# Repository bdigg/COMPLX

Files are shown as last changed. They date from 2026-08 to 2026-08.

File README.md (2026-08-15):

# COMPLX Control Software

COMPLX is the control software for a robotic-microfluidic platform for
combinatorial lipid nanoparticle formulation. It coordinates a DOBOT MG400 input
robot, pressure-driven microfluidic flow control, Arduino-compatible collection
hardware, experiment scheduling, live status updates, and run logging for
plate-based formulation workflows.

This repository accompanies the manuscript *A robotic-microfluidic platform for
combinatorial access to millions of lipid nanoparticle formulations*. It
contains the Python control software, Arduino firmware, public configuration
templates, example experiment import data, and the hardware bill of materials
in `Part Files and BOM/`.

## Platform Overview

COMPLX combines three hardware subsystems:

- DOBOT MG400 robotic input handling for loading lipid stocks and carrying out
  automated line changes.
- Elveflow OB1 pressure-driven microfluidic control with inline flow sensing.
- Arduino-controlled output hardware for plate collection and valve actuation.

The software communicates with the DOBOT over TCP/IP, with the Elveflow OB1
through the manufacturer Python interface, and with the collection stage and
servo-actuated valves through serial communication. Hardware addresses, COM
ports, calibration values, and control parameters are stored in `configs/`, so
the platform can be adapted without modifying source code.

In the workflow described in the associated paper, COMPLX is used to select from
lipid stock libraries, generate or import formulation spaces, assign output
wells in 96- or 384-well plate layouts, schedule stock changes, control
microfluidic formulation, and record full run data.

## Installation And Setup

These instructions assume the hardware has been assembled as described in the
associated manuscript and supplementary methods.

### 1. Install Conda

Install a 64-bit Conda distribution for Windows.

### 2. Create A Python Environment

Create and activate a dedicated environment:

```powershell
conda create -n complx python=3.12
conda activate complx
```

Python 3.11 or newer is expected. Python 3.12.2 was used for the manuscript
experiments.

### 3. Install Python Packages

Install the Python dependencies:

```powershell
python -m pip install -r requirements.txt
```

### 4. Install Elveflow Software And Drivers

Install the Elveflow software, SDK, runtime components, and drivers for the OB1
controller and flow sensors:

https://elveflow.com/microfluidic-applications/setup-environment-elveflow-sdk/

Elveflow vendor files are not included in this repository. Users must obtain
them from Elveflow and install them locally. The COMPLX Python modules expect the
Elveflow Python wrapper (`Elveflow64.py`) and 64-bit DLL/runtime files to be
available locally before connecting to the OB1.

### 5. Set Up The DOBOT MG400

Install DOBOT Studio Pro and connect the MG400 over Ethernet:

https://www.dobot-robots.com/service/download-center

Configure the robot controller network settings, then load and run the included
`dobotserver.lua` script on the DOBOT before connecting from the COMPLX software.

Perform setup and calibration of the robotic arm as described in the manuscript
methods.

### 6. Set Up The Arduino Hardware

Install the Arduino IDE. In the Arduino IDE:

- Connect the Arduino controlling the collection stage.
- Select the correct board and COM port.
- Upload `arduino/arduino.ino`.
- If secondary valves are used, upload `arduino/arduino_secondary_valves.ino` to
  the secondary controller.

The collection-stage and valve controllers communicate with COMPLX over serial.
The manuscript workflow used serial communication at 115200 baud. If multiple
serial devices are attached, select the intended COM ports in the GUI or local
configuration before running automated collection.

### 7. Configure Local Settings

Hardware and app settings must be configured in the GUI before operation. The
GUI saves these selections and calibration values in `configs/` for reuse.

Key local settings include:

- Elveflow controller identifiers and optional extra pressure-controller
  settings.
- DOBOT IP address and port.
- Arduino COM ports for the collection stage and secondary valves.
- Sensor channel assignments and correction coefficients.
- Pressure limits, flow-control gains, timing parameters, and flush settings.
- Plate format, starting position, excluded wells, and plate calibration.

The saved config files will contain local serial numbers, COM ports, IP
addresses, calibration arrays, and run settings.

## Running COMPLX

From this folder, with the environment activated:

```powershell
python main.py
```

or, after editable installation:

```powershell
complx
```

The GUI creates runtime folders as needed and uses the configuration files in
`configs/` for hardware and run settings.

## Operating Workflow

The typical operating method follows this general sequence:

1. Start the hardware systems and launch COMPLX in the configured Conda
   environment by running main.py.
2. Connect to the pressure controller, DOBOT, collection stage, and valve
   microcontrollers through the software interface.
3. Select a user configuration defining timing, flow-control settings, sensor
   calibration, pressure limits, and active hardware.
4. Populate the digital lipid library with stock names, identifiers,
   concentrations, display colours, input-plate positions, and loading volumes.
5. Fill the corresponding input wells with the required lipid stock volume plus
   excess dead volume for robotic loading, then seal wells as required by the
   hardware workflow.
6. Record the aqueous phase or buffer and connect the buffer reservoir to the
   microfluidic manifold.
7. Create experiments in the GUI or import them from CSV. Each experiment defines
   lipid stocks, component ratios, total flow rate, flow-rate ratio, collection
   volume, repeats, and output wells.
8. Confirm output plate format, destination wells, excluded positions, and
   collection-plate placement.
9. Connect the microfluidic device to the lipid inlets, aqueous inlet, and
   particle outlet.
10. Inspect tubing, reservoirs, waste routing, robotic alignment, collection
   stage position, and plate seating.
11. Prime or flush lines, start the queue, and monitor live flow, pressure,
   robot, and collection status.
12. After completion, remove collection plates and run the final cleaning
   procedure.

## Outputs

During use the software creates local runtime and output folders:

- `logs/` - finalized JSON logs and run indexes.
- `FlowData/` - run folders, parameter records, flow traces, plots, and Excel
  logs.

For each formulation, the logging system records identifiers, lipid identities,
programmed compositions, assigned input and output wells, target and measured
flow rates, pressure set points, collection volume, equilibration and expulsion
timing, run events, status, and time-series flow data.

## Admin Tools

The GUI includes admin tools for setup, calibration, and troubleshooting. These
tools allow manual control of selected hardware functions, including DOBOT
movement, gripper and valve outputs, collection-stage movement, plate-position
calibration, sensor checks, priming, and cleaning routines.

Admin tools should be used only by trained operators during setup or fault
recovery. Confirm that pressure is safe, the collection stage is clear, and the
robot work envelope is unobstructed before using manual movement controls.

## First Run Checks

Before allowing pressure control or movement:

- Confirm tubing, reservoirs, waste routing, and chip connections are secure.
- Confirm pressure limits in `configs/app/config.json` are conservative for the
  chip and formulation.
- Confirm sensor channels and correction coefficients match the connected
  hardware.
- Confirm collection plate calibration and starting well are correct.
- Confirm the DOBOT, Arduino hardware, and Elveflow hardware can be stopped
  manually.
- Confirm destination wells are empty and the plate is correctly seated.
- Confirm the microfluidic outlet is directed to waste during priming and
  failure recovery.

## Safety Checklist

- Ensure a full local risk assessment is in place before operating the COMPLX
  platform.
- Verify tubing, reservoirs, waste routing, and chip connections before enabling
  pressure.
- Use conservative `p_range`, `p_incr`, and flow-rate values when testing new
  chips, sensors, or formulations.
- Keep hands clear of the robot and collection stage during automated motion.
- Confirm collection wells are empty before automated dispensing.
- Confirm pressure and robot emergency-stop procedures before unattended runs.
- Stop the run immediately if flow readings, pressure readings, or robot motion
  do not match the expected state.

## License

This software is released under the MIT License. See `LICENSE`.

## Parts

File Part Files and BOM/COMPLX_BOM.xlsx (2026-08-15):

Mechanical and Electronic
Item | Number | Description | Supplier | Link | Cost/Unit | Total
Robot Arm | 1 | With electromagnetic gripper | Robot Shop | https://uk.robotshop.com/products/dobot-mg400-robotic-arm | £1846.15 | £1846.15
Linear Actuator | 3 | 500mm | Ooznest | https://ooznest.co.uk/product/mini-v-linear-actuator-kit/#length | £47.54 | £142.62
Motor | 3 | 1704HS168AW-AB NEMA 17 stepper motor, 1.8°/step, 1.68 A, approximately 3.5 kg·cm. | Ooznest | With above, inc cable | £17.82 | £53.46
Motor Driver | 4 | DFRobot DRI0043 / TB6600 stepper driver, four units, configured to 0.5 A and 1/4 microstepping | Farnell | https://uk.farnell.com/dfrobot/dri0043/stepper-motor-driver-4a-9v-to/dp/3517878 | £18.18 | £72.72
Arduino | 2 | 2x Nano Every or 1x Uno | RS | https://uk.rs-online.com/web/p/arduino/1927590?gb=a | £11.18 | £22.36
12V DC Supply | 3 | 12 V DC, 1.5 A, 18 W | RS | https://uk.rs-online.com/web/p/ac-dc-adapters/1753310 | £10.42 | £31.26
Cable Mount | 5 |  | RS | https://uk.rs-online.com/web/p/dc-power-connectors/1792860 | £2.94 | £14.70
Mini Vacuum | 1 | AIRPO D2028B miniature vacuum pump, 12 V DC | Mouser | https://www.mouser.co.uk/ProductDetail/SparkFun/ROB-10398?qs=WyAARYrbSnaW%252B0ieELD1FQ%3D%3D | £20.96 | £20.96
Servo Motors | 10 | SG90 micro servo, 5 V | RS | https://uk.rs-online.com/web/p/stem-motion-components/2153180 | £4.04 | £40.40
Z-Axis Linear Actuator | 1 | Portescap two-phase stepper linear actuator, 8.9 N force, 48 mm travel, 12 V | RS | https://uk.rs-online.com/web/p/electric-linear-actuators/5101091?searchId=2ede3070-08aa-4e1e-927f-483a743afa06 | £108.77 | £108.77
Motor Cables | 4 | 4-Core Cables ( | RS | https://ooznest.co.uk/product/1000mm-nema17-hybrid-bipolar-stepper-motor-wire/ | £2.40 | £9.60
Limit Switch | 3 | With cables | Ooznest | https://ooznest.co.uk/product/micro-limit-switch/ | £2.50 | £7.50
Breadboard | 2 | Will require jumper wires (either soldered or solderless) | RS | https://uk.rs-online.com/web/p/breadboards/2153175 | £4.14 | £8.28
Micro USB Cable | 2 |  | RS | https://uk.rs-online.com/web/p/usb-cables/1828496 | £3.48 | £6.96
Microfluidic
Item | Number | Description | Supplier | Link | Cost/Unit | Total
Eleveflow OB1 | 1 | Four channels, 0-2bar | Darwin Microfluidics | https://darwin-microfluidics.com/products/ob1-mk4-flow-controller | £9909.30 | £9909.30
Bottle Reservoir Cap | 1 | For 1L Duran Bottle, PTFE | Darwin Microfluidics | https://darwin-microfluidics.com/products/microfluidic-caps-and-glass-reservoir-bottle | £129.70 | £129.70
40ml Reservoir Cap | 3 | For 40ml Falcon Tubes | Darwin Microfluidics | https://darwin-microfluidics.com/products/50-ml-falcon-tube-microfluidic-reservoir-m-2-4-port | £134.50 | £403.50
1/4-28 Flangless Fittings | 3 | (Pack of 10 inc ferrules) | Darwin Microfluidics | https://darwin-microfluidics.com/products/microfluidic-flangeless-fittings-1-4-28-to-1-16-od-tubing | £47.12 | £141.36
10-32 Flangless Fittings | 1 | For lipid library nozzle connections | Darwin Microfluidics | https://darwin-microfluidics.com/products/10-32-flat-bottom-peek-fittings-ferrules-pack-of-10 | £69.47 | £69.47
Male Luer to Barbed Adapter | 1 | For gas line connection | Darwin Microfluidics | https://darwin-microfluidics.com/products/male-luer-to-barbed-adapter-10-pack-pp/ | £8.00 | £8.00
1/4-28 to Barbed | 1 |  | Darwin Microfluidics | https://darwin-microfluidics.com/products/1-4-28-swivel-to-3-32-id-adapter-for-4-mm-tubing | £44.88 | £44.88
1/4-28 Union
Whisper Valves 3/2 | 3 | With 1/4-28 Fittings | Darwin Microfluidics | https://darwin-microfluidics.com/products/3-2-way-bistable-whisper-valve-type-6724/ | £141.90 | £425.70
Flow Sensor (1000ul/min) | 1 |  | Mouser | https://www.mouser.co.uk/ProductDetail/Sensirion/LG16-1000D-1000-ul-min?qs=xZ%2FP%252Ba9zWqakiDmqzvSsnA%3D%3D | £499.89 | £499.89
Flow Sensor (7ul/min) | 3 |  | Mouser | https://www.mouser.co.uk/ProductDetail/Sensirion/LG16-0150D-7000-nl-min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 | £499.99 | £1499.97
Tygon ND 100-80 Tubing | 5 | Various Sizes required (0.25x0.76,0.51x1.52,1.02x1.78,1.27x2.29) | Darwin Microfluidics | https://darwin-microfluidics.com/products/tygon-nd-100-80-micro-tubing | £30.10 | £150.50
Silicone Tubing | 1 | 0.5*0.8. For pinch valve | Darwin Microfluidics | https://darwin-microfluidics.com/products/platinum-cured-silicone-tubing-15-m | £42.90 | £42.90
Large Silicone Tubing | 1 | For gas lines | RS | https://uk.rs-online.com/web/p/hose-pipe-flexible-tubes/4189999?gb=a | £76.03 | £76.03
Capiliary Tubing | 1 | 1/16" 65 micron ID. 15m | Darwin Microfluidics | https://darwin-microfluidics.com/products/1-16-od-peek-capillary-tubing | £39.08 | £39.08
Tygon S3 3603 | 1 | 1.6 x 3.2 mm. For pinch valve coupling | Darwin Microfluidics | https://darwin-microfluidics.com/products/tygon-s3-e-3603-tubing | £21.50 | £21.50
Barbed T-junction | 1 | 1/16" (10 pack) | Darwin Microfluidics | https://darwin-microfluidics.com/products/t-barbed-adapter-10-pack-pp/ | £6.40 | £6.40
Bubble Sensors | 3 | 10 week lead time (Mouser alternate supplier) | Farnell | https://uk.farnell.com/panasonic/be-a201p/optical-bubble-sensor-2mm-tube/dp/4077840 | £79.57 | £238.71
O-Rings | 3 | For lipid library nozzles (7 mm ID, 10mm OD) | RS | https://uk.rs-online.com/web/p/products/1965657/
Silicone Stoppers | 45 |  | Fisher Scientific | https://www.fishersci.co.uk/shop/products/standard-bungs-silicone-rubber/30286536 | £0.53 | £23.85
Custom Made Parts
Material | Number | Description | Supplier | Link | Cost/Unit | Total
Gantry Top-Mount | 1 | PLA 3D Print | In House | CAD in repository | -
Pinch Valve Holders | 2 | PLA 3D Print - 1x6 + 1x3 | In House | CAD in repository | -
Reservoir Holders | 1 | PLA 3D Print | In House | CAD in repository | -
Solenoid Valve Rack | 1 | PLA 3D Print | In House | CAD in repository | -
Flow Sensor Rack | 1 | PLA 3D Print | In House | CAD in repository | -
Well plate holder | 7 | PLA 3D Print - 1xDock, 6x plate holders | In House | CAD in repository | -
Flow Switch Plate | 1 | Resin 3D Print | In House | CAD in repository | -
Manifold Plate | 1 | 316 Stainess, Machined | In House | CAD in repository | -
End Effector Pincers | 2 | 6061 Aluminium, Machined | In House | CAD in repository | -
Manifold Nozzles | 3 | 316 Stainess, Machined | In House | CAD in repository | -
 |  |  |  |  | Total | £14270.33
 |  |  |  |  | Total - OB1 | £4361.03

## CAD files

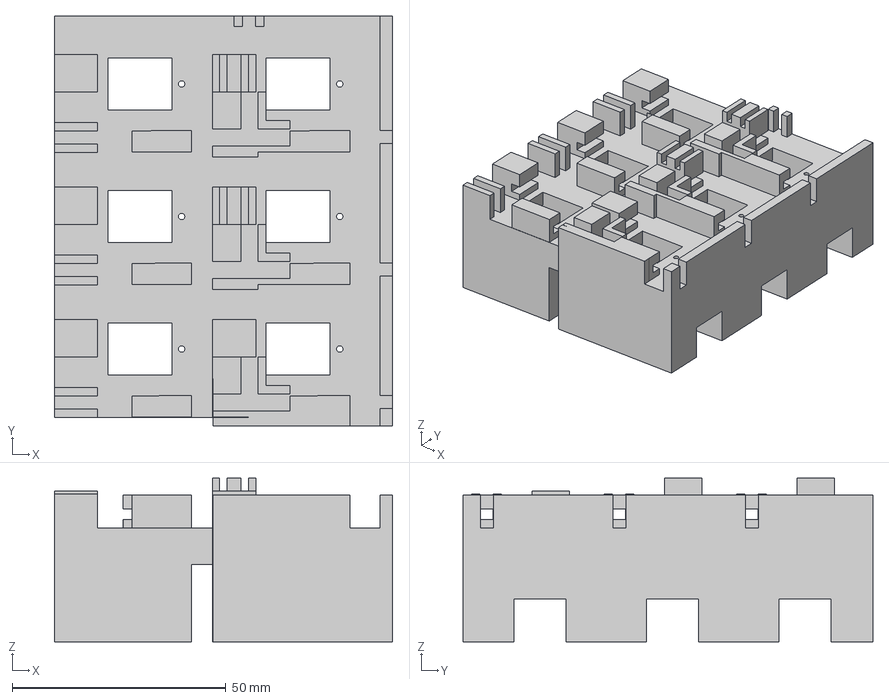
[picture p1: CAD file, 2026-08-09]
Part Files and BOM/PinchValve_Six.step
79.1 x 95.9 x 38.3 mm

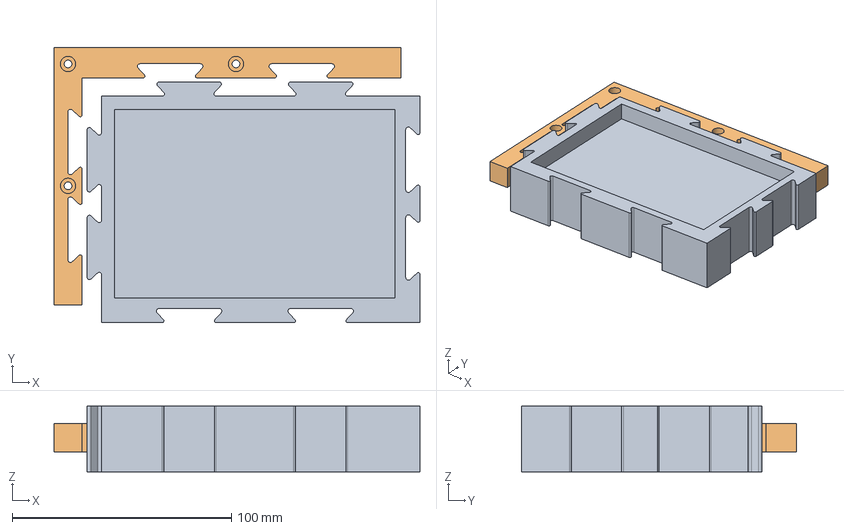
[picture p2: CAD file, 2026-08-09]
Part Files and BOM/Wellplate_Holder.step
166.9 x 125.6 x 30.0 mm

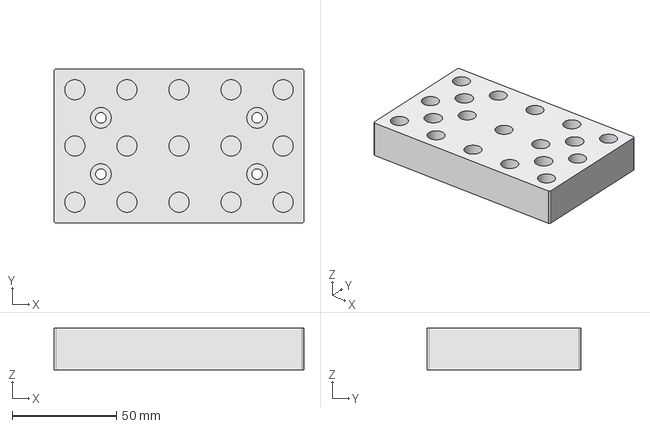
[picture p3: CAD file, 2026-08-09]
Part Files and BOM/Input_Plate_5x3.step
120.0 x 74.0 x 20.0 mm

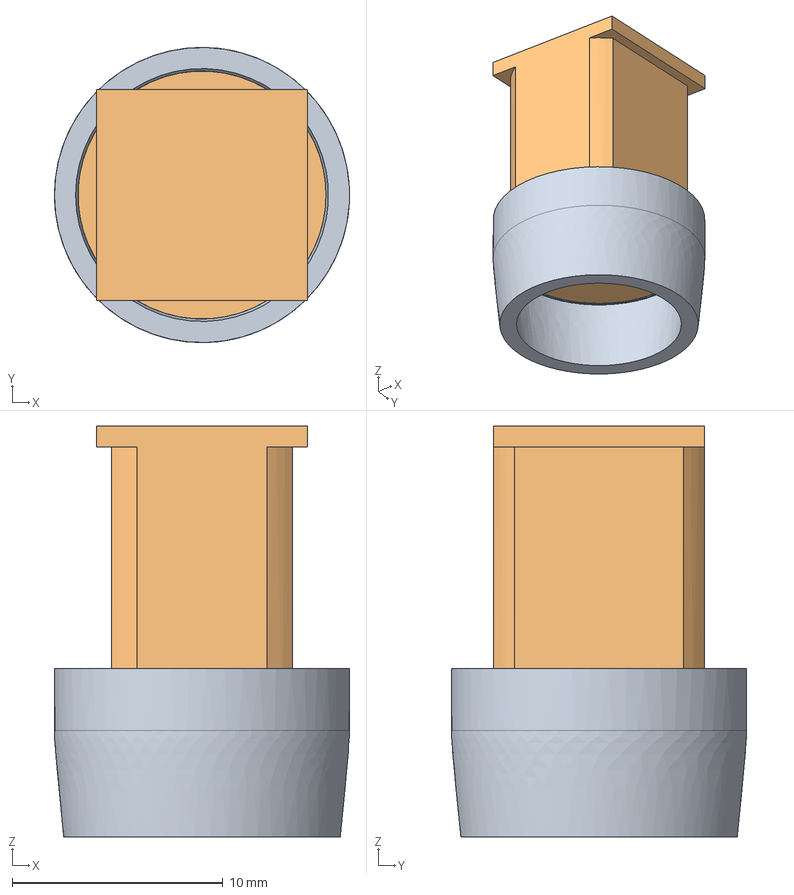
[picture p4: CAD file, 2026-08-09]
Part Files and BOM/Stopper.step
14.0 x 14.0 x 19.5 mm

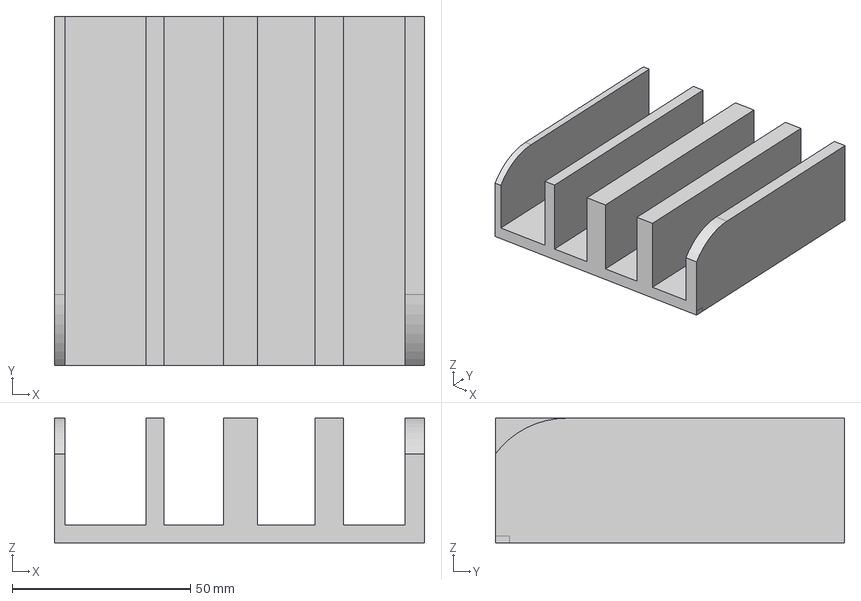
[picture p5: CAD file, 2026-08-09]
Part Files and BOM/Sensor_Holder.step
104.0 x 98.0 x 35.0 mm

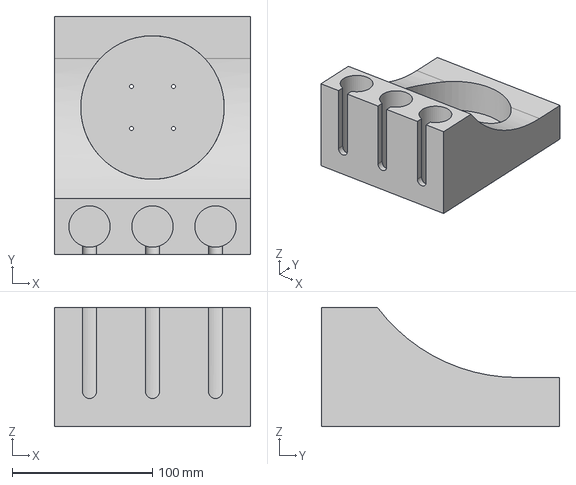
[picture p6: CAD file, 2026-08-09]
Part Files and BOM/Reservoir_Stand.step
140.0 x 170.0 x 85.0 mm

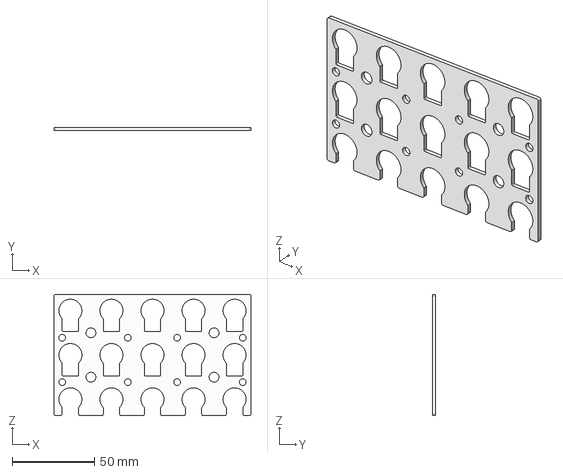
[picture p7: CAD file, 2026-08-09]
Part Files and BOM/Input_Plate_TopSheet.step
120.0 x 2.00 x 74.0 mm

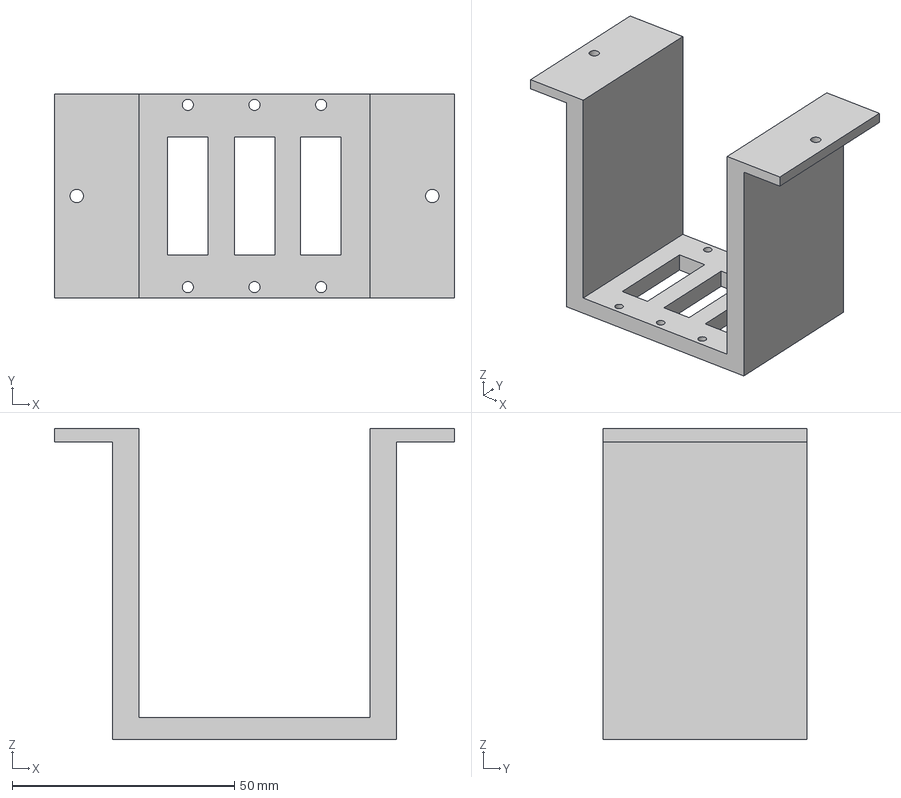
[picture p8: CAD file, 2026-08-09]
Part Files and BOM/SolenoidValve_Holder.step
90.0 x 46.0 x 70.0 mm

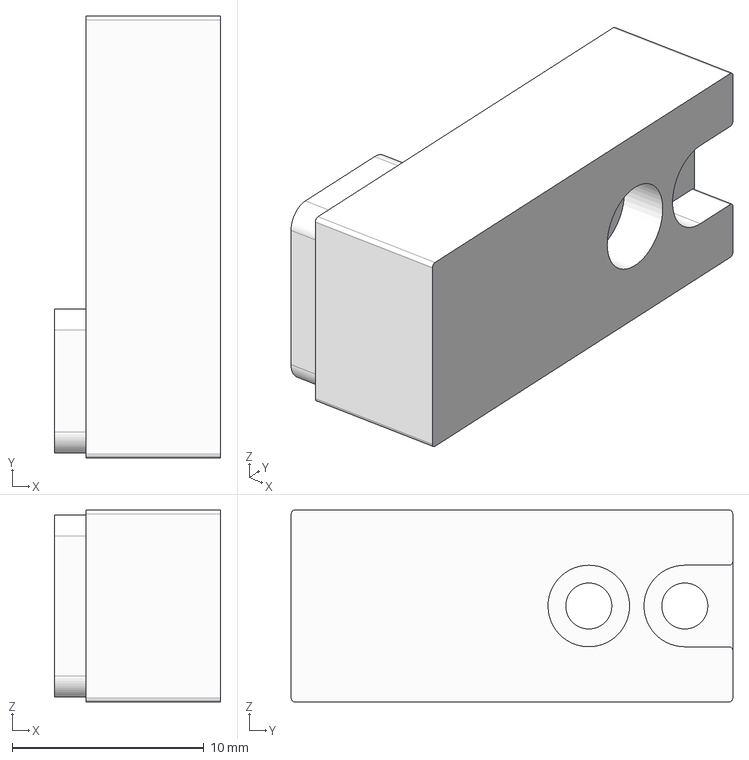
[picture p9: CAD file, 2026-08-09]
Part Files and BOM/Electromagentic_Gripper_Pincer.step
8.65 x 23.0 x 10.0 mm

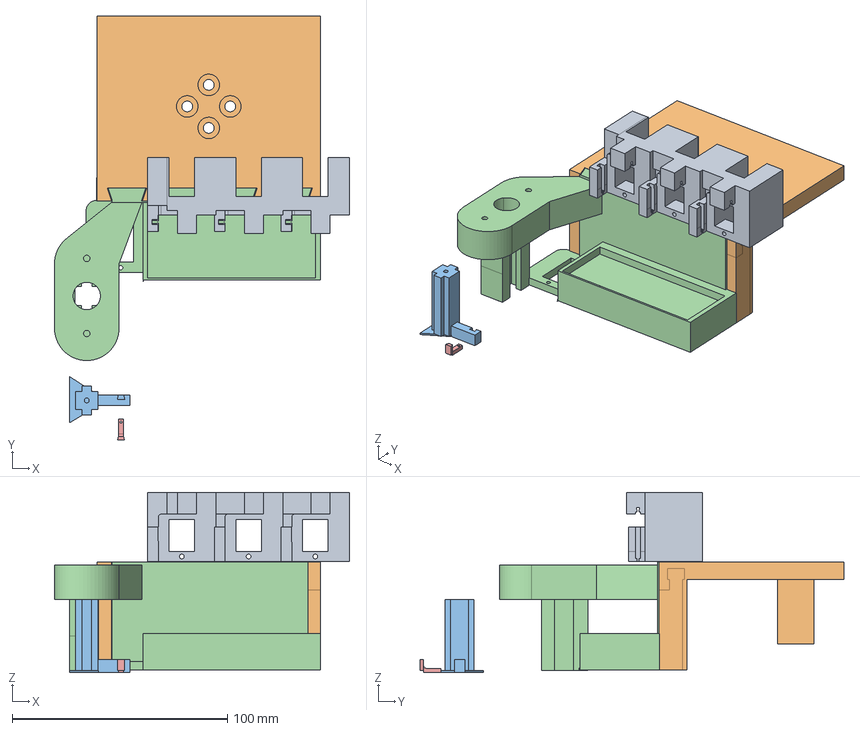
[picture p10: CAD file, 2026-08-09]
Part Files and BOM/TopMount_AllParts.step
137.0 x 196.9 x 83.7 mm

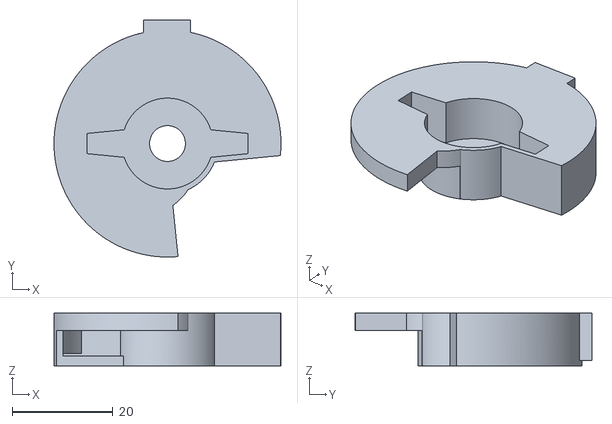
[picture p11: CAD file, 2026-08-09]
Part Files and BOM/ServoFlowSwitch_AutoMHF.stl
45.0 x 47.0 x 10.5

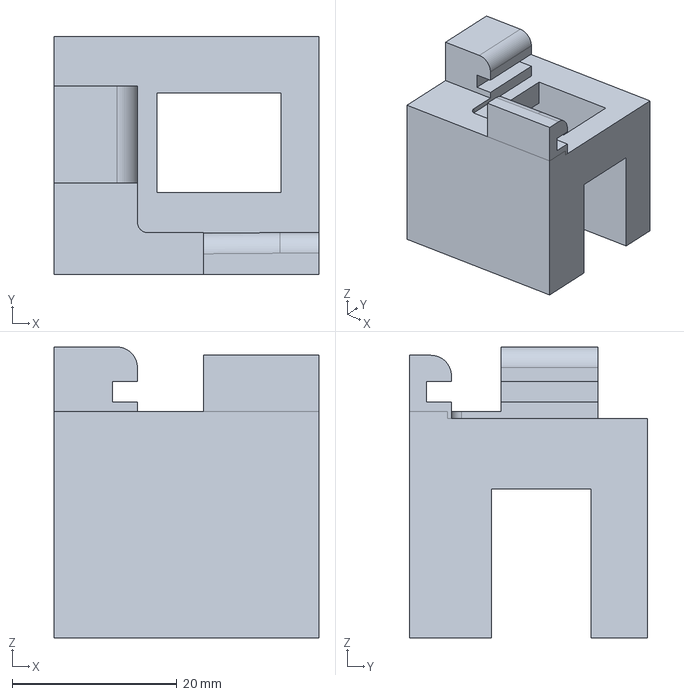
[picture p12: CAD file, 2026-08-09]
Part Files and BOM/PinchValve_Single.step
32.1 x 28.9 x 35.3 mm

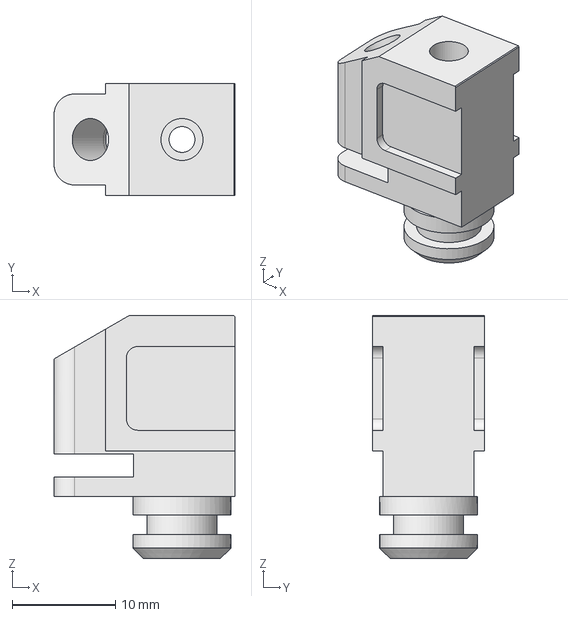
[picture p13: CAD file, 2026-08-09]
Part Files and BOM/Input_Nozzle.step
17.5 x 10.8 x 23.5 mm

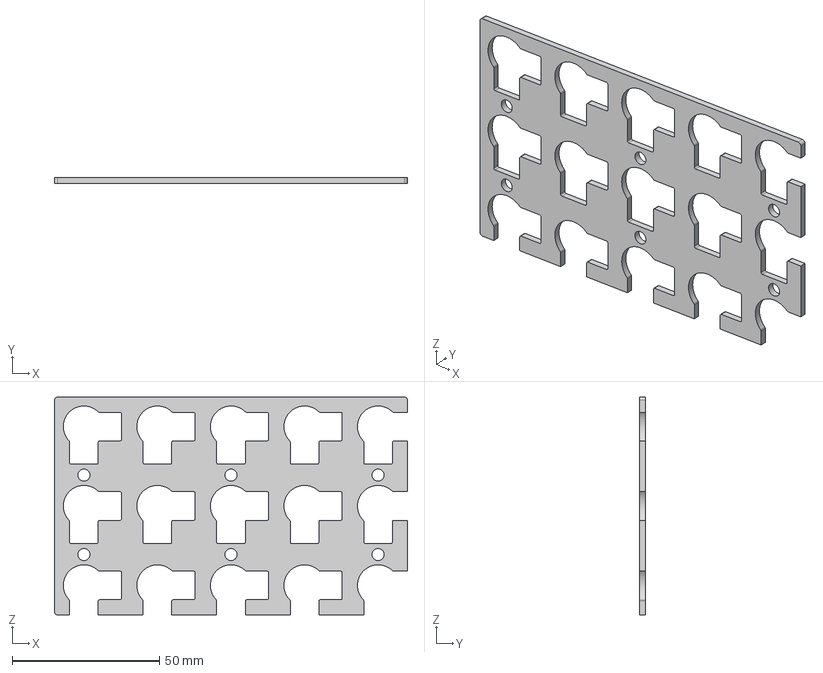
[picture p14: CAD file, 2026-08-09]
Part Files and BOM/Input_Plate_BottomSheet.step
120.0 x 2.00 x 74.0 mm

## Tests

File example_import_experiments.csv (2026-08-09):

experiment_name | Screening_A
line1_code | line1_comp | line2_code | line2_comp | line3_code | line3_comp | tfr | frr | volume | repeats
DOPC5 | 60 | DPPC7 | 40 | None | 0 | 480 | 60 | 100 | 1
DOPC5 | 40 | DPPC7 | 60 | None | 0 | 480 | 60 | 100 | 1
DOPC5 | 20 | DPPC7 | 80 | None | 0 | 480 | 60 | 100 | 1

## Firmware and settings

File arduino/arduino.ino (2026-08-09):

// Adapted from Niall McIntyre 2023 (Adapted from Nick Brooks)
// Updated: removed flow-switch code; added extra servos on pins 11,12,13,17,18,19
#include <ezButton.h>
#include <Servo.h>

const byte numChars = 32;
char receivedChars[numChars];

char messageFromPC = 0;
float floatFromPC1 = 0.0;
float floatFromPC2 = 0.0;
float floatFromPC3 = 0.0;
boolean newData = false;

// Stepper + syringe pins
const int dirPin1 = 2;
const int stepPin1 = 3;
const int dirPin2 = 5;
const int stepPin2 = 6;
const int dirPin3 = 8;
const int stepPin3 = 9;

const int servopin = 14;     // KEEP CURRENT SERVO (unchanged behavior)
const int syrdirpin = 15;
const int syrsteppin = 16;

const int motorSpeed = 1000;

// Limit switches
const int ls1 = 4;
const int ls2 = 7;
const int ls3 = 10;

ezButton limitSwitch1(ls1);
ezButton limitSwitch2(ls2);
ezButton limitSwitch3(ls3);

// ---------------- Servo setup ----------------

// Current servo (UNCHANGED behavior: still uses 0/1 sweep)
Servo myservo;
int pos = 0;

// Extra servos with angle control on pins: 11,12,13,17,18,19
const int extraServoPin1 = 11;
const int extraServoPin2 = 12;
const int extraServoPin3 = 13;
const int extraServoPin4 = 17;
const int extraServoPin5 = 18;
const int extraServoPin6 = 19;

Servo extraServo1, extraServo2, extraServo3, extraServo4, extraServo5, extraServo6;
// Power-up defaults:
// - Valves 1-3 closed to dobot (40 deg)
// - Valves 4-6 keep previous neutral default (80 deg)
int extraPos1 = 40, extraPos2 = 40, extraPos3 = 40, extraPos4 = 80, extraPos5 = 80, extraPos6 = 80;

// ---------------- Motor functions ----------------

void setMotorHorzDirection(int value) {
  digitalWrite(dirPin1, value);
  Serial.println("Turnt1");
}

void setMotorVertDirection(int value) {
  digitalWrite(dirPin3, value);
  if (value == 0) value = 1;
  else value = 0;
  digitalWrite(dirPin2, value);
  Serial.println("Turnt2");
}

void SyringeMove(int direction, int distance, int wait) {
  digitalWrite(syrdirpin, direction);
  for (int x = 0; x < distance; x++) {
    digitalWrite(syrsteppin, HIGH);
    delayMicroseconds(wait);
    digitalWrite(syrsteppin, LOW);
    delayMicroseconds(wait);
  }
  Serial.println("Moved Syringe");
}

void setDistanceHorz(int distance) {
  for (int x = 0; x < distance; x++) {
    digitalWrite(stepPin1, HIGH);
    delayMicroseconds(motorSpeed);
    digitalWrite(stepPin1, LOW);
    delayMicroseconds(motorSpeed);
  }
  Serial.println("Moved1");
}

void setDistanceHorzLS(int distance, int speed) {
  for (int x = 0; x < distance; x++) {
    digitalWrite(stepPin1, HIGH);
    delayMicroseconds(speed);
    digitalWrite(stepPin1, LOW);
    delayMicroseconds(speed);
  }
}

void setDistanceVert(int distance) {
  for (int x = 0; x < distance; x++) {
    digitalWrite(stepPin2, HIGH);
    delayMicroseconds(motorSpeed);
    digitalWrite(stepPin2, LOW);
    delayMicroseconds(motorSpeed);

    digitalWrite(stepPin3, HIGH);
    delayMicroseconds(motorSpeed);
    digitalWrite(stepPin3, LOW);
    delayMicroseconds(motorSpeed);
  }
  Serial.println("Moved2");
}

void setDistanceVertLeft_LS(int distance, int speed) {
  for (int x = 0; x < distance; x++) {
    digitalWrite(stepPin2, HIGH);
    delayMicroseconds(speed);
    digitalWrite(stepPin2, LOW);
    delayMicroseconds(speed);
  }
}

void setDistanceVertRight_LS(int distance, int speed) {
  for (int x = 0; x < distance; x++) {
    digitalWrite(stepPin3, HIGH);
    delayMicroseconds(speed);
    digitalWrite(stepPin3, LOW);
    delayMicroseconds(speed);
  }
}

void setMotorHorzDirectionLS(int value) {
  digitalWrite(dirPin1, value);
}

void setMotorVertDirectionLeft_LS(int value) {
  if (value == 0) value = 1;
  else value = 0;
  digitalWrite(dirPin2, value);
}

void setMotorVertDirectionRight_LS(int value) {
  digitalWrite(dirPin3, value);
}

void setDistanceBoth(int distance1, int distance2) {
  int steps1 = abs(distance1);
  int steps2 = abs(distance2);

  for (int x = 0; x < max(steps1, steps2); x++) {
    if (x < steps1) {
      digitalWrite(stepPin1, HIGH);
      delayMicroseconds(motorSpeed);
      digitalWrite(stepPin1, LOW);
      delayMicroseconds(motorSpeed);
    }
    if (x < steps2) {
      digitalWrite(stepPin2, HIGH);
      delayMicroseconds(motorSpeed);
      digitalWrite(stepPin2, LOW);
      delayMicroseconds(motorSpeed);

      digitalWrite(stepPin3, HIGH);
      delayMicroseconds(motorSpeed);
      digitalWrite(stepPin3, LOW);
      delayMicroseconds(motorSpeed);
    }
  }
  Serial.println("Moved Both");
}

// ---------------- Homing ----------------

void Homing() {
  bool isStopped1 = false;
  bool isStopped2 = false;
  bool isStopped3 = false;
  bool isStopped4 = false;
  bool isStopped5 = false;
  bool isStopped6 = false;

  while (!isStopped1) {
    limitSwitch1.loop();

    setMotorHorzDirectionLS(1);
    setMotorVertDirectionRight_LS(1);
    setMotorVertDirectionLeft_LS(1);

    setDistanceHorzLS(1, 1000);

    if (limitSwitch1.isPressed()) isStopped1 = true;
  }

  if (isStopped1) {
    delay(1000);
    setMotorHorzDirectionLS(0);
    setDistanceHorzLS(50, 1000);
    setMotorHorzDirectionLS(1);
    delay(1000);

    while (!isStopped2) {
      limitSwitch1.loop();
      setDistanceHorzLS(1, 1000);
      delay(100);
      if (limitSwitch1.isPressed()) isStopped2 = true;
    }
  }

  if (isStopped2) {
    delay(1000);

    while (!isStopped3 || !isStopped5) {
      limitSwitch2.loop();
      limitSwitch3.loop();

      if (!isStopped3) {
        setDistanceVertLeft_LS(1, 1000);
        if (limitSwitch2.isPressed()) isStopped3 = true;
      }
      if (!isStopped5) {
        setDistanceVertRight_LS(1, 1000);
        if (limitSwitch3.isPressed()) isStopped5 = true;
      }
    }

    if (isStopped3 || isStopped5) {
      delay(1000);
      setMotorVertDirectionLeft_LS(0);
      setMotorVertDirectionRight_LS(0);
      setDistanceVertLeft_LS(100, 1000);
      setDistanceVertRight_LS(100, 1000);
      setMotorVertDirectionLeft_LS(1);
      setMotorVertDirectionRight_LS(1);
      delay(1000);

      while (!isStopped4 || !isStopped6) {
        limitSwitch2.loop();
        limitSwitch3.loop();
        delay(100);

        if (!isStopped4) {
          setDistanceVertLeft_LS(1, 1000);
          if (limitSwitch2.isPressed()) isStopped4 = true;
        }
        if (!isStopped6) {
          setDistanceVertRight_LS(1, 1000);
          if (limitSwitch3.isPressed()) isStopped6 = true;
        }
      }
    }
  }
}

// ---------------- Current servo (UNCHANGED) ----------------

void servo(int value) {
  if (value == 0) {
    for (pos = 0; pos <= 69; pos += 1) {
      myservo.write(pos);
      delay(15);
    }
  }
  if (value == 1) {
    for (pos = 69; pos >= 0; pos -= 1) {
      myservo.write(pos);
      delay(15);
    }
  }
}

// ---------------- New servo angle control (for extra servos) ----------------

const int SERVO_STEP = 1;      // degrees per step
const int SERVO_DELAY_MS = 15; // delay between steps (ms)

void moveServoToAngle(Servo &s, int targetAngle, int &currentAngle) {
  targetAngle = constrain(targetAngle, 0, 180);

  if (targetAngle > currentAngle) {
    for (int a = currentAngle; a <= targetAngle; a += SERVO_STEP) {
      s.write(a);
      delay(SERVO_DELAY_MS);
    }
  } else {
    for (int a = currentAngle; a >= targetAngle; a -= SERVO_STEP) {
      s.write(a);
      delay(SERVO_DELAY_MS);
    }
  }
  s.write(targetAngle);
  currentAngle = targetAngle;
}

// servoNumber: 1..6 maps to pins: 11,12,13,17,18,19
void setExtraServoAngle(int servoNumber, int angle) {
  switch (servoNumber) {
    case 1: moveServoToAngle(extraServo1, angle, extraPos1); break; // 11
    case 2: moveServoToAngle(extraServo2, angle, extraPos2); break; // 12
    case 3: moveServoToAngle(extraServo3, angle, extraPos3); break; // 13
    case 4: moveServoToAngle(extraServo4, angle, extraPos4); break; // 17
    case 5: moveServoToAngle(extraServo5, angle, extraPos5); break; // 18
    case 6: moveServoToAngle(extraServo6, angle, extraPos6); break; // 19
    default: Serial.println("Bad Servo #"); break;
  }
}

// ---------------- Serial receive + parse ----------------

void recvWithStartEndMarkers() {
  static boolean recvInProgress = false;
  static byte ndx = 0;
  char startMarker = '<';
  char endMarker = '>';
  char rc;

  while (Serial.available() > 0 && newData == false) {
    rc = Serial.read();

    if (recvInProgress == true) {
      if (rc != endMarker) {
        receivedChars[ndx] = rc;
        ndx++;
        if (ndx >= numChars) ndx = numChars - 1;
      } else {
        receivedChars[ndx] = '\0';
        recvInProgress = false;
        ndx = 0;
        newData = true;
      }
    } else if (rc == startMarker) {
      recvInProgress = true;
    }
  }
}

// Safe parsing (supports 0..3 numbers after command)
void parseData() {
  messageFromPC = receivedChars[0];

  char *tok;

  tok = strtok(receivedChars + 1, ",");
  floatFromPC1 = (tok != NULL) ? atof(tok) : 0;

  tok = strtok(NULL, ",");
  floatFromPC2 = (tok != NULL) ? atof(tok) : 0;

  tok = strtok(NULL, ",");
  floatFromPC3 = (tok != NULL) ? atof(tok) : 0;
}

// ---------------- Command processing ----------------

void showParsedData() {
  if (messageFromPC == 'M') {
    setMotorHorzDirection((int)floatFromPC1);
  } else if (messageFromPC == 'N') {
    setMotorVertDirection((int)floatFromPC1);
  } else if (messageFromPC == 'L') {
    setDistanceHorz((int)floatFromPC1);
  } else if (messageFromPC == 'P') {
    setDistanceVert((int)floatFromPC1);
  } else if (messageFromPC == 'B') {
    setDistanceBoth((int)floatFromPC1, (int)floatFromPC2);
  } else if (messageFromPC == 'H') {
    Homing();
  } else if (messageFromPC == 'S') {
    servo((int)floatFromPC1);   // KEEP OLD SERVO CONTROL (0/1)
  } else if (messageFromPC == 'X') {
    SyringeMove((int)floatFromPC1, (int)floatFromPC2, (int)floatFromPC3);
  } else if (messageFromPC == 'A') {
    // NEW: <A,servoNumber,angle>
    setExtraServoAngle((int)floatFromPC1, (int)floatFromPC2);
  } else {
    Serial.println("?");
  }
}

// ---------------- Setup + loop ----------------

void setup() {
  pinMode(stepPin1, OUTPUT);
  pinMode(dirPin1, OUTPUT);

  pinMode(stepPin2, OUTPUT);
  pinMode(dirPin2, OUTPUT);

  pinMode(stepPin3, OUTPUT);
  pinMode(dirPin3, OUTPUT);

  pinMode(syrdirpin, OUTPUT);
  pinMode(syrsteppin, OUTPUT);

  // Attach servos
  myservo.attach(servopin);              // existing servo (pin 14) unchanged

  extraServo1.attach(extraServoPin1);    // pin 11
  extraServo2.attach(extraServoPin2);    // pin 12
  extraServo3.attach(extraServoPin3);    // pin 13
  extraServo4.attach(extraServoPin4);    // pin 17
  extraServo5.attach(extraServoPin5);    // pin 18
  extraServo6.attach(extraServoPin6);    // pin 19

  // Initialize extra servos to their tracked positions.
  extraServo1.write(extraPos1);
  extraServo2.write(extraPos2);
  extraServo3.write(extraPos3);
  extraServo4.write(extraPos4);
  extraServo5.write(extraPos5);
  extraServo6.write(extraPos6);

  Serial.begin(115200);
  while (!Serial) { delay(1); }
  Serial.println("We are Connected");
  Serial.println("Init: valves 1-3 set to 40 (closed to dobot)");
}

void loop() {
  recvWithStartEndMarkers();
  if (newData == true) {
    parseData();
    showParsedData();
    newData = false;
  }
}

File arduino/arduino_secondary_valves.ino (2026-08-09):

// Secondary microcontroller sketch for valves 7, 8, 9 only.
// Command format matches existing Python code:
//   <A,servoNumber,angle>
// Supported servo numbers:
//   7 -> pin 10
//   8 -> pin 9
//   9 -> pin 8

#include <Servo.h>

const byte NUM_CHARS = 32;
char receivedChars[NUM_CHARS];
bool newData = false;

char messageFromPC = 0;
float floatFromPC1 = 0.0;
float floatFromPC2 = 0.0;
float floatFromPC3 = 0.0;

Servo valve7;
Servo valve8;
Servo valve9;

int pos7 = 80;
int pos8 = 80;
int pos9 = 80;

const int SERVO_STEP = 1;
const int SERVO_DELAY_MS = 15;

void moveServoToAngle(Servo &s, int targetAngle, int &currentAngle) {
  targetAngle = constrain(targetAngle, 0, 180);

  if (targetAngle > currentAngle) {
    for (int a = currentAngle; a <= targetAngle; a += SERVO_STEP) {
      s.write(a);
      delay(SERVO_DELAY_MS);
    }
  } else {
    for (int a = currentAngle; a >= targetAngle; a -= SERVO_STEP) {
      s.write(a);
      delay(SERVO_DELAY_MS);
    }
  }

  s.write(targetAngle);
  currentAngle = targetAngle;
}

void setValveAngle(int servoNumber, int angle) {
  switch (servoNumber) {
    case 7: moveServoToAngle(valve7, angle, pos7); break;
    case 8: moveServoToAngle(valve8, angle, pos8); break;
    case 9: moveServoToAngle(valve9, angle, pos9); break;
    default:
      Serial.println("Bad Servo #");
      return;
  }
  Serial.println("OK");
}

void recvWithStartEndMarkers() {
  static bool recvInProgress = false;
  static byte ndx = 0;
  const char startMarker = '<';
  const char endMarker = '>';
  char rc;

  while (Serial.available() > 0 && !newData) {
    rc = Serial.read();

    if (recvInProgress) {
      if (rc != endMarker) {
        receivedChars[ndx] = rc;
        ndx++;
        if (ndx >= NUM_CHARS) ndx = NUM_CHARS - 1;
      } else {
        receivedChars[ndx] = '\0';
        recvInProgress = false;
        ndx = 0;
        newData = true;
      }
    } else if (rc == startMarker) {
      recvInProgress = true;
    }
  }
}

void parseData() {
  messageFromPC = receivedChars[0];

  char *tok;
  tok = strtok(receivedChars + 1, ",");
  floatFromPC1 = (tok != NULL) ? atof(tok) : 0;

  tok = strtok(NULL, ",");
  floatFromPC2 = (tok != NULL) ? atof(tok) : 0;

  tok = strtok(NULL, ",");
  floatFromPC3 = (tok != NULL) ? atof(tok) : 0;
}

void showParsedData() {
  if (messageFromPC == 'A') {
    setValveAngle((int)floatFromPC1, (int)floatFromPC2);
  } else {
    Serial.println("?");
  }
}

void setup() {
  valve7.attach(10);
  valve8.attach(9);
  valve9.attach(8);

  valve7.write(pos7);
  valve8.write(pos8);
  valve9.write(pos9);

  Serial.begin(115200);
  while (!Serial) { delay(1); }
  Serial.println("Secondary valves ready");
}

void loop() {
  recvWithStartEndMarkers();
  if (newData) {
    parseData();
    showParsedData();
    newData = false;
  }
}

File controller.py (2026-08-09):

from model import AppModel
from status_manager import StatusManager
from config_manager import ConfigManager
from queue_manager import QueueManager
from robot_sequencer import RobotSequencer
from plate_tracker import PlateTracker
from data_logger import DataLogger
from status_broker import StatusBroker
from microfluidic_controller import MicrofluidicController
import time
import random
from robot_loader import RobotClient, RobotLoader
import threading
import os
import json
import csv
import io
from lipid_tracker import LipidTracker
from typing import List, Tuple, Dict, Optional
import ast
import re
import itertools

class ControlAPI:
    def __init__(self):
        self.model = AppModel()
        self.status_mgr = StatusManager()
        self.config_mgr = ConfigManager()
        self.status_broker = StatusBroker()
        self.data_logger = DataLogger()
        self.lipid_manager = LipidTracker()
        self.plate_tracker = PlateTracker()
        self.queue_manager = QueueManager(self.config_mgr)
        self.robot_sequencer = RobotSequencer(self.lipid_manager)
        self.robot_sequencer.set_status_callback(self._on_robot_sequencer_status)
        self.robot_sequencer.set_error_callback(self._on_robot_fault)
        self.robot_sequencer.set_line_status_callback(self.status_broker.set_line_status)
        self.microfluidic_ctrl = MicrofluidicController(
            self.status_broker, 
            self.data_logger, 
            self.lipid_manager,
            on_composition_complete=self._on_composition_complete,
            on_experiment_complete=self._on_experiment_complete
        )
        self.gui = None
        self._last_used = self.config_mgr.load_config("app", "last_used") or {}
        self._queue_thread = None
        self._queue_stop = threading.Event()
        self._queue_running = False
        self._start_lock = threading.Lock()
        self._skip_loading = False
        self._start_well = (1, 1, 1)
        self._app_config = self.config_mgr.load_config("app", "config") or {}
        selected_cfg = self.config_mgr.load_config("app", "selected_config") or {}
        self._selected_config_preset = str(selected_cfg.get("name") or "").strip() or None
        self._plate_calibration = self.config_mgr.load_config("app", "plate_calibration") or {}
        self.microfluidic_ctrl.set_plate_calibration(self._plate_calibration)
        self.robot_sequencer.set_remove_stoppers_enabled(bool(self._app_config.get("Remove Stoppers", False)))
        self._buffer_selected_name = None
        self._clean_lock = threading.Lock()
        self._clean_state = {1: "Idle", 2: "Idle", 3: "Idle"}
        self._loaded_lines_this_exp = set()
        self._last_load_failure = None
        self._recovery_lock = threading.Lock()
        self._dobot_recovery_active = False
        self._dobot_recovery_context = None
        self._dobot_recovery_continue = threading.Event()
        self._active_log_exp_id = None
        self._admin_motion_lock = threading.Lock()
        self._admin_motion_thread = None
        self._random_dobot_lock = threading.Lock()
        self._random_dobot_thread = None
        self._random_dobot_stop = threading.Event()
        
        # Clear lipid allocations unless resuming from checkpoint
        if not self.has_checkpoint():
            self.clear_lipid_allocations()

    def set_gui(self, gui):
        self.gui = gui

    def toggle_connection(self, name):
        connected = self.model.toggle_connection(name)
        return connected

    def get_lipid_configs(self):
        return self.config_mgr.list_configs("lipids")

    def _enrich_lipid_entries_with_codes(self, lipid_entries: List[Dict]) -> List[Dict]:
        """Best-effort attach `lipid_code` from lipid library config to runtime lipid entries."""
        out: List[Dict] = []
        for entry in (lipid_entries or []):
            if not isinstance(entry, dict):
                out.append(entry)
                continue
            item = dict(entry)
            name = str(item.get("name") or "").strip()
            if name and not str(item.get("lipid_code") or "").strip():
                try:
                    cfg = self.load_lipid_config(name) or {}
                    code = str(cfg.get("lipid_code") or "").strip().upper()
                    if code:
                        item["lipid_code"] = code
                except Exception:
                    pass
            out.append(item)
        return out

    def save_lipid_config(self, name, data):
        code = str((data or {}).get("lipid_code", "")).strip().upper()
        if code:
            if not re.fullmatch(r"[A-Z0-9]+", code):
                raise ValueError("Lipid code must contain only A-Z and 0-9 (no spaces).")
            for other_name in self.get_lipid_configs():
                if other_name == name:
                    continue
                other_cfg = self.load_lipid_config(other_name) or {}
                other_code = str(other_cfg.get("lipid_code", "")).strip().upper()
                if other_code and other_code == code:
                    raise ValueError(f"Lipid code '{code}' is already used by '{other_name}'.")
            data = dict(data or {})
            data["lipid_code"] = code
        self.config_mgr.save_config("lipids", name, data)

    def load_lipid_config(self, name):
        return self.config_mgr.load_config("lipids", name)

    def get_microfluidics_configs(self):
        return self.config_mgr.list_configs("microfluidics")

    def save_microfluidics_config(self, name, data):
        self.config_mgr.save_config("microfluidics", name, data)

    def get_dobot_configs(self):
        return self.config_mgr.list_configs("dobot")

    def save_dobot_config(self, name, data):
        self.config_mgr.save_config("dobot", name, data)

    def get_buffer_configs(self):
        return self.config_mgr.list_configs("buffers")

    def save_buffer_config(self, name, data):
        self.config_mgr.save_config("buffers", name, data)

    def set_status(self, state, message=""):
        self.status_mgr.set_status(state, message)
        status_text = f"{state} - {message}" if message else state
        self.status_broker.set_ui_status(status_text)
        if self.gui:
            self.gui.status_label.setText(f"Status: {status_text}")

    def get_status(self):
        return self.status_broker.get_status()

    def get_experiment_record_number(self, exp_id: str) -> Optional[int]:
        """Best-effort lookup of the records folder numeric ID assigned at run start."""
        try:
            exp = self.queue_manager.get_experiment(str(exp_id))
            if exp and getattr(exp, "record_id", None) is not None:
                return int(exp.record_id)
        except Exception:
            pass
        try:
            return self.data_logger.get_record_number(str(exp_id))
        except Exception:
            return None
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

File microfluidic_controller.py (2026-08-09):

import threading
import queue
import time
import numpy as np
from typing import Optional, List, Dict, Tuple
import pump
import expel
from concurrent.futures import ThreadPoolExecutor
import ast
from elveflow_extra import ElveflowExtraPump

class MicrofluidicController:
    """Background microfluidic control loop with pause/resume/skip."""
    
    def __init__(self, status_broker, data_logger, lipid_tracker, on_composition_complete=None, on_experiment_complete=None):
        self.status_broker = status_broker
        self.data_logger = data_logger
        self.lipid_tracker = lipid_tracker
        self.on_composition_complete = on_composition_complete  # Callback(exp_id, comp_idx)
        self.on_experiment_complete = on_experiment_complete  # Callback(exp_id) when all compositions done
        
        # Command queue for GUI -> control loop
        self.command_queue: queue.Queue = queue.Queue()
        
        # State
        self.is_running = False
        self.is_paused = False
        self.should_skip = False
        self.control_thread: Optional[threading.Thread] = None
        self._stop_requested = False
        self._re_eq_required = False
        
        # Hardware handles (microfluidics only)
        self.ser = None
        self.ser_secondary = None
        self.calibarr = None
        
        # Control parameters
        self.active_channels = [1, 2, 3, 4]
        self.sensorcorr = [[0,0,0,1.0897,-1.2766],[0.2673,-0.8813,1.3205,1.1869,-0.2],[0.2673,-0.8813,1.3205,1.1869,-0.2],[0.2673,-0.8813,1.3205,1.1869,-0.2]]
        self.period = 0.5
        self.K_p = np.array([0.5, 500, 500, 500])
        self.K_i = 0.001
        self.p_incr = [-100, 100]
        self.p_range = [0, 2000]
        self.flush_frs = [420, 4, 4, 4]
        self.start_flush1_frs = [420, 4, 4, 4]
        self.start_flush2_frs = [420, 4, 4, 4]
        self.start_flush = True
        self.zero_flush = False
        self.start_flush_ramp_enabled = True
        self.zero_flush_ramp_enabled = True
        self.zero_flow_blocking = True
        self.min_nonzero_set_fr = 0.25
        self.prime_buffer_fr = 100.0
        self.prime_lipid_fr = 20.0
        self.prime_rna_buffer_fr = 20.0
        self.rna_buffer_startflush_fr = 0.0
        self.rna_buffer_zeroflush_fr = 0.0
        
        # Current experiment state
        self.current_exp_id: Optional[str] = None
        self.current_composition_idx = 0
        self.collected_volume = 0.0
        self.target_volume = 100.0
        self.last_stable_pressures = [0, 0, 0, 0]
        self._start_well = (1, 1, 1)  # Add missing initialization
        self._current_well: Optional[Tuple[int, int, int]] = None
        self._manual_current_well: Optional[Tuple[int, int, int]] = None
        self._just_finished_priming = False  # Flag to keep servos in waste after priming
        self._last_primed_lines = set()
        self._last_prime_set_fr_full = None
        self.prime_to_startflush_ramp_s = 60.0
        self.flush_time_s = 0.0
        self.first_comp_delay_s = 0.0
        self.zero_block_hold_s = 3.0
        self.equilibration_retry = False
        self.maxfrerror = [100, 0.2]
        self.extra_pump = ElveflowExtraPump()
        self.extra_pump_connected = False
        self.extra_flow_last = None
        self.extra_pressure_last = 0.0
        self.extra_flow_kp = 3000.0
        self.extra_flow_ki = 0.001
        self.sensorcorr_extra_rna = [0.2673, -0.8813, 1.3205, 1.1869, -0.2]
        
        # Thread pool for non-blocking hardware movements
        self.hw_executor = ThreadPoolExecutor(max_workers=1)
        self.plate_calibration = {}
        self._config = {}  # Store current config

    def set_plate_calibration(self, plate_calibration: Dict) -> None:
        """Set per-plate calibration map {plate: {stepsH, stepsV}}."""
        self.plate_calibration = plate_calibration or {}

    def _get_plate_calibration(self, plate: int) -> Optional[Dict[str, float]]:
        plate_key = str(plate)
        return self.plate_calibration.get(plate_key) or self.plate_calibration.get(plate)

    def jog_stage(self, dir_h: str, dir_v: str, steps_h: int, steps_v: int) -> None:
        """Jog stage by steps (blocking)."""
        if not self.ser:
            raise RuntimeError("Microcontroller not connected - cannot move stage")
        expel.move(self.ser, dir_h, dir_v, steps_h, steps_v)

    def home_to_plate(self, plate: int) -> None:
        """Home the stage, then move to calibrated first well for a plate if defined."""
        if not self.ser:
            raise RuntimeError("Microcontroller not connected - cannot home stage")
        calib = self._get_plate_calibration(plate)
        if calib and "stepsH" in calib and "stepsV" in calib:
            expel.home(self.ser)
            expel.setstep(self.ser, calib["stepsH"], calib["stepsV"])
        else:
            expel.home(self.ser)

    def set_manual_current_well(self, well: Tuple[int, int, int]) -> None:
        """Track current well for manual moves and update status."""
        self._manual_current_well = well
        self._current_well = well
        self.status_broker.set_current_well(well[1], well[2], well[0])

    def move_to_well(self, target_well: Tuple[int, int, int], rehome: bool = False) -> Tuple[int, int, int]:
        """Move to a well for manual testing (optionally re-home first)."""
        if not self.ser:
            raise RuntimeError("Microcontroller not connected - cannot move stage")
        if rehome or self._manual_current_well is None:
            self._home_and_move_to_well(target_well)
        else:
            self._manual_current_well = self._move_to_well_sync(self._manual_current_well, target_well)
        self._manual_current_well = target_well
        self._current_well = target_well
        self.status_broker.set_current_well(target_well[1], target_well[2], target_well[0])
        return target_well

    def enter_calibration_mode(self, z_down_steps: int = int(1300 * 2 / 3)) -> None:
        """Switch to collect mode and lower Z for calibration."""
        if not self.ser:
            raise RuntimeError("Microcontroller not connected - cannot enter calibration")
        expel.servoswitch(self.ser, 1)
        expel.movez(self.ser, "Down", int(z_down_steps), 400)

    def exit_calibration_mode(self, z_up_steps: int = 1300) -> None:
        """Raise Z and return to waste mode after calibration."""
        if not self.ser:
            return
        expel.movez(self.ser, "Up", int(z_up_steps), 400)
        expel.servoswitch(self.ser, 0)
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

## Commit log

2026-08-09 COMPLX GUI Software Upload
    [Electromagentic_Gripper_Pincer.step, Input_Nozzle.step, Input_Plate_5x3.step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]
2026-08-15 Add BOM, detailed README, license
    [COMPLX_BOM.xlsx, Electromagentic_Gripper_Pincer.step, Input_Nozzle.step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]
